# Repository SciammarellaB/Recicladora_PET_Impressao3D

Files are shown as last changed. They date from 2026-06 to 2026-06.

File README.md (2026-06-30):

# Recicladora PET para Impressão 3D

Projeto de TCC voltado ao desenvolvimento de uma recicladora doméstica capaz de
transformar garrafas PET pós-consumo em filamento utilizável em impressoras 3D
FDM.

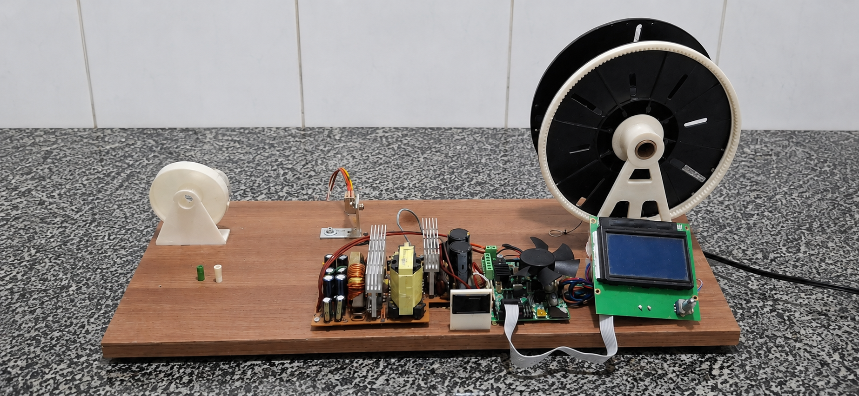
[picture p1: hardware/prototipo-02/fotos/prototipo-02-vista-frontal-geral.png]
Protótipo 02 da recicladora PET


## Índice

- [Sobre o projeto](#sobre-o-projeto)
- [Demonstração de funcionamento](#demonstração-de-funcionamento)
- [Motivação](#motivação)
- [Prova de conceito manual](#prova-de-conceito-manual)
- [Como o processo funciona](#como-o-processo-funciona)
- [Protótipos](#protótipos)
- [Vídeos do projeto](#vídeos-do-projeto)
- [Preparação do PET](#preparação-do-pet)
- [Peças impressas em 3D](#peças-impressas-em-3d)
- [Montagem dos subconjuntos](#montagem-dos-subconjuntos)
- [Extrusão e controle dimensional](#extrusão-e-controle-dimensional)
- [Primeira impressão com PET](#primeira-impressão-com-pet)
- [Controle por G-code](#controle-por-g-code)
- [Anexos e referências](#anexos-e-referências)
- [Estrutura do repositório](#estrutura-do-repositório)
- [Licença](#licença)
- [Observações técnicas](#observações-técnicas)

## Sobre o projeto

A proposta deste projeto é demonstrar, na prática, que uma garrafa PET comum pode
ser preparada, cortada em fitas, extrudada e transformada em material para
impressão 3D.

O foco não está apenas na reciclagem do plástico, mas na construção de um ciclo
completo e acessível: sair de um resíduo cotidiano e chegar a uma peça impressa
funcional. Para isso, o projeto reúne modelagem 3D, reaproveitamento de
componentes de impressora, eletrônica, controle por G-code, testes de extrusão e
ajustes de impressão.

## Demonstração de funcionamento

O vídeo abaixo mostra o equipamento em operação, com a fita PET sendo alimentada
na recicladora, o acionamento do sistema e o início da transformação da fita em
filamento para impressão 3D.

<a href="https://www.youtube.com/shorts/rl4tyrrVXBk" target="_blank" rel="noopener noreferrer">Assistir à demonstração no YouTube</a>

## Motivação

Filamentos comerciais representam um custo recorrente para quem utiliza
impressão 3D. Ao mesmo tempo, garrafas PET são resíduos amplamente disponíveis e
com potencial técnico para reaproveitamento.

A recicladora foi desenvolvida para investigar uma pergunta simples:

> É possível transformar garrafas PET pós-consumo em filamento funcional para
> impressão 3D usando uma solução doméstica, de baixo custo e reproduzível?

O projeto também tem um objetivo educacional: documentar o processo de forma
clara para que outras pessoas possam entender as decisões de construção, os
testes realizados e os limites encontrados.

## Prova de conceito manual

Antes da construção dos protótipos, o primeiro teste foi feito de forma manual
para verificar se o princípio do projeto era possível.

Foi utilizado o bloco gerador de calor do hotend E3D, segurado com um alicate de
pressão, e uma placa RAMPS para controlar o aquecimento. A ideia era simples: se
a fita de PET conseguisse passar pelo bloco aquecido e sair em formato de
filamento, então faria sentido avançar para a construção de uma recicladora com
estrutura, motor, carretel e controle por G-code.

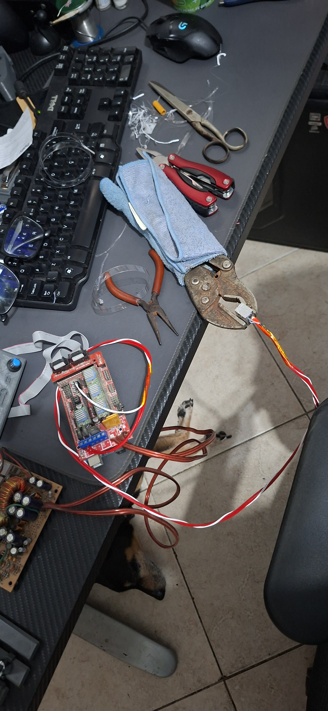
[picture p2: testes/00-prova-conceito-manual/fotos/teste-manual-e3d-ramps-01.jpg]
Prova de conceito manual com bloco E3D e RAMPS


Com o primeiro trecho de filamento puxado manualmente, o material foi testado na
impressora para verificar se o sistema conseguiria aceitá-lo, tanto pelo diâmetro
quanto pela temperatura de trabalho.

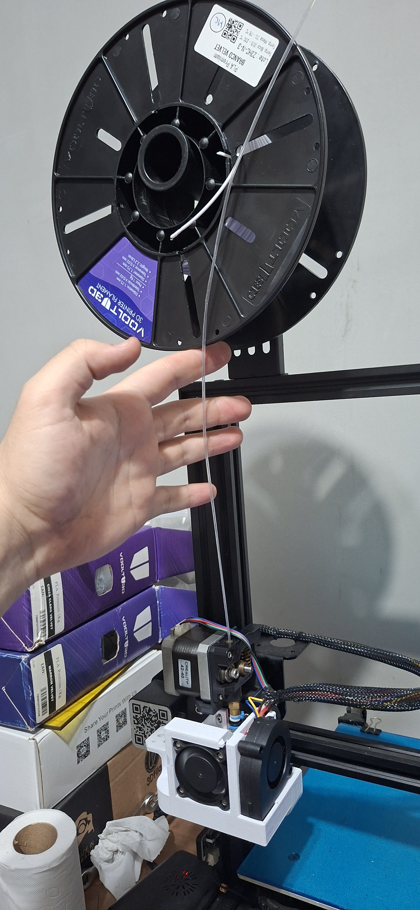
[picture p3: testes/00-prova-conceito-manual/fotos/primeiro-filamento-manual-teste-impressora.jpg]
Primeiro filamento manual sendo testado na impressora


A documentação desta etapa está em
[testes/00-prova-conceito-manual](testes/00-prova-conceito-manual/).

## Como o processo funciona

O processo começa com a seleção e preparação das garrafas. Depois, o PET é
cortado em fitas, aquecido no hotend, conformado em formato de filamento e
enrolado em um carretel adaptado. O material produzido é então testado em uma
impressora 3D, exigindo ajustes próprios de temperatura, fluxo e velocidade.

## Protótipos

### Protótipo 01

O primeiro protótipo validou a montagem inicial do sistema de bobinamento, a
transmissão por engrenagens e o controle eletrônico usando RAMPS 1.4 com Arduino
Mega, LCD compatível com RAMPS e fonte ATX reaproveitada de computador.

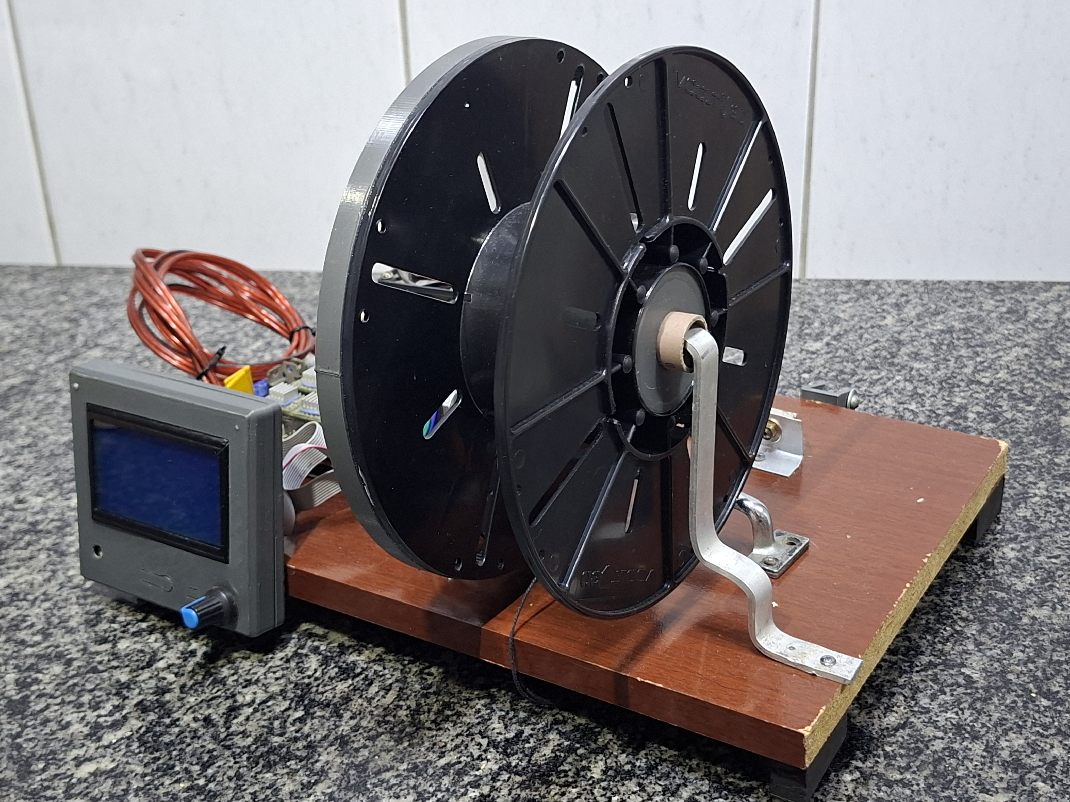
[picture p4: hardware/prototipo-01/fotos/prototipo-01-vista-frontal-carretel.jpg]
Protótipo 01 da recicladora PET


Nesta versão, o equipamento chegou a funcionar de forma estável: bastava iniciar
o G-code e aguardar o processo de extrusão/bobinamento terminar.

Mais fotos e detalhes estão em [hardware/prototipo-01](hardware/prototipo-01/).

### Protótipo 02

O segundo protótipo reorganiza a montagem em uma base maior, separando melhor as
etapas de alimentação do material, aquecimento, eletrônica de controle e
bobinamento.

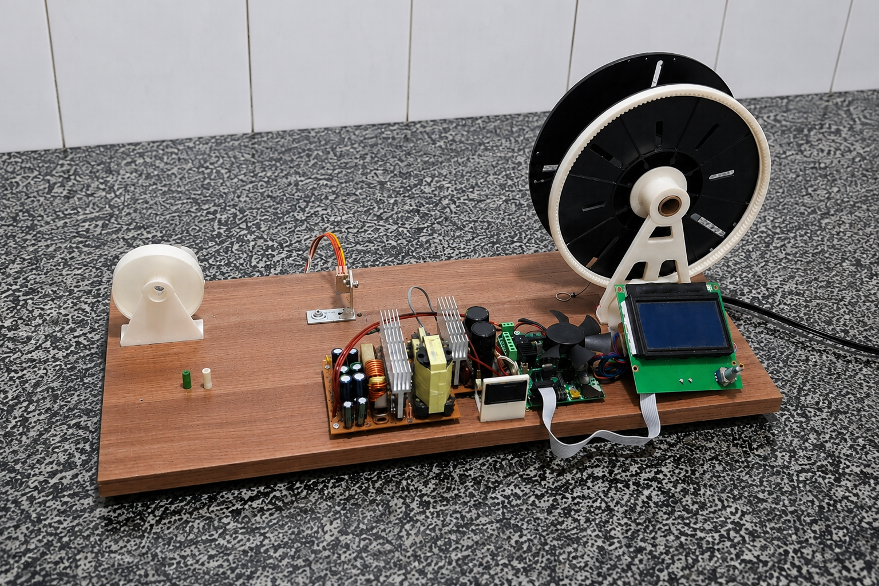
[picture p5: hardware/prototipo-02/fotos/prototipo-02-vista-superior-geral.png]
Protótipo 02 em vista superior


Após montar o conjunto do motor e fixar o carretel nos suportes, foi feito um
teste para verificar o alinhamento e o giro do conjunto mecânico.

Com a montagem validada, o protótipo 2 passou a funcionar corretamente, sem
ajustes pendentes para a operação normal.

Mais fotos e detalhes estão em [hardware/prototipo-02](hardware/prototipo-02/).

## Vídeos do projeto

| Vídeo | Referência no projeto | YouTube |
| --- | --- | --- |
| Protótipo 01 funcionando corretamente | [Protótipo 01](hardware/prototipo-01/#video-de-funcionamento) | <a href="https://youtube.com/shorts/Gr8xRWNqr9U" target="_blank" rel="noopener noreferrer">Assistir</a> |
| Protótipo 02 - teste do motor e carretel | [Teste de montagem](hardware/prototipo-02/#teste-de-montagem) | <a href="https://youtube.com/shorts/MNewDyZXh2g" target="_blank" rel="noopener noreferrer">Assistir</a> |
| Protótipo 02 funcionando corretamente | [Funcionamento correto](hardware/prototipo-02/#funcionamento-correto) | <a href="https://www.youtube.com/watch?v=FplmZ49YgME" target="_blank" rel="noopener noreferrer">Assistir</a> |
| Preparação da garrafa PET para fatiamento | [Preparação do PET](testes/01-preparacao-pet/) | <a href="https://www.youtube.com/shorts/VywLTE21x4Y" target="_blank" rel="noopener noreferrer">Assistir</a> |
| Processo de transformação da fita PET em filamento | [Extrusão e controle dimensional](testes/02-extrusao/) | <a href="https://www.youtube.com/shorts/rl4tyrrVXBk" target="_blank" rel="noopener noreferrer">Assistir</a> |
| Primeira impressão com filamento PET reciclado | [Primeiro teste de impressão](testes/03-impressao-3d/#primeiro-teste-de-impressão) | <a href="https://www.youtube.com/shorts/xxXg9N6lQYA" target="_blank" rel="noopener noreferrer">Assistir</a> |
| Benchy com PET de garrafa colorida | [Teste com PET colorido](testes/03-impressao-3d/#teste-com-pet-colorido) | <a href="https://www.youtube.com/watch?v=Nncd09i17XM" target="_blank" rel="noopener noreferrer">Assistir</a> |
| Impressão do suporte do switch da fita PET | [Peças funcionais](pecas-impressas/funcionais/#suporte-do-switch-da-fita-pet) | <a href="https://youtu.be/djwcRPlRVBY" target="_blank" rel="noopener noreferrer">Assistir</a> |
| Suporte do carretel da fita PET | [Peças funcionais](pecas-impressas/funcionais/#suporte-do-carretel-da-fita-pet) | <a href="https://youtu.be/MDmy_xOUEg0" target="_blank" rel="noopener noreferrer">Assistir</a> |

## Preparação do PET

Antes do corte em tiras, as garrafas precisam ser limpas, secas e preparadas. A
retirada do rótulo é importante para evitar que papel, adesivo, cola ou sujeira
contaminem a fita de PET e cheguem ao hotend durante a extrusão.

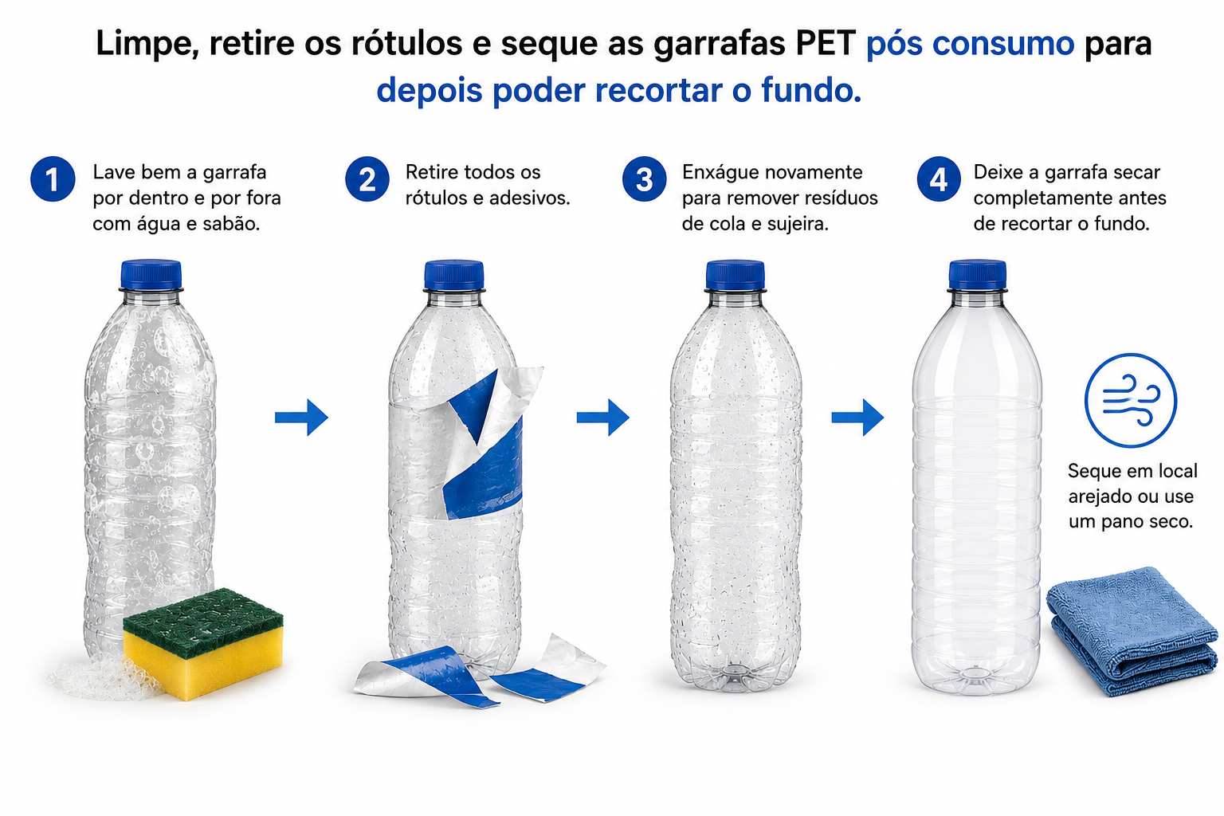
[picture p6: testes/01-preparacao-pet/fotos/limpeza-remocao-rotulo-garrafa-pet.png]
Limpeza e remoção do rótulo da garrafa PET


Depois da limpeza, o fundo da garrafa é removido para permitir o encaixe correto
na ferramenta de corte das tiras de PET.

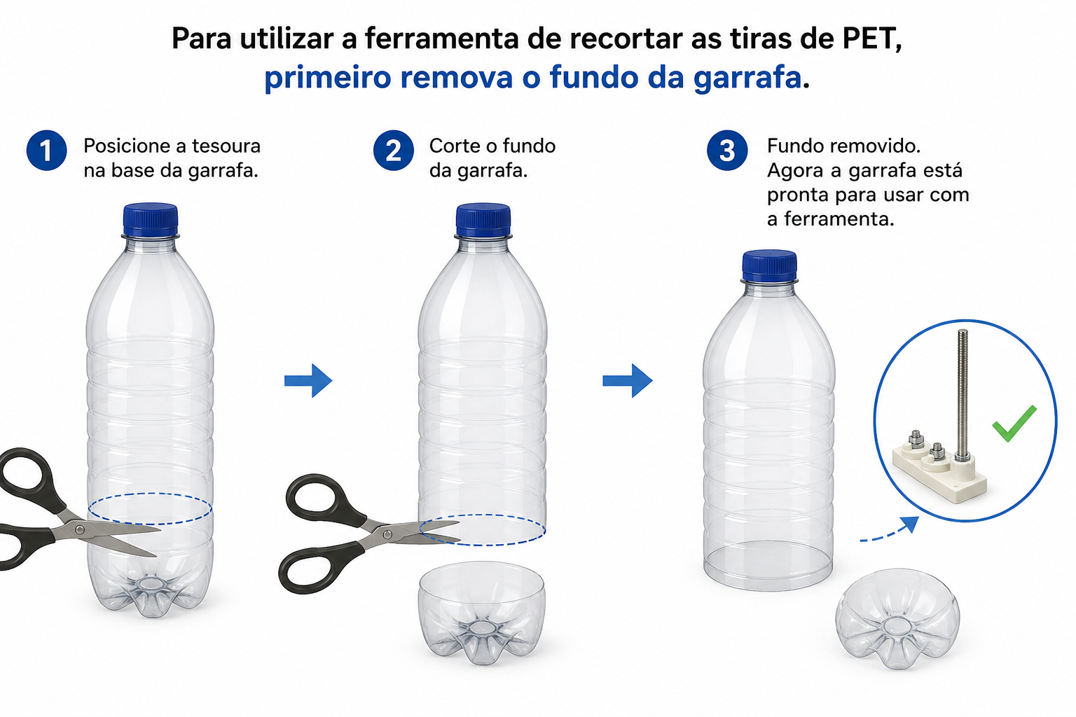
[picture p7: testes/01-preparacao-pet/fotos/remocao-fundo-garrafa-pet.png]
Remoção do fundo da garrafa PET


Para o fatiamento da garrafa em tiras, foi utilizado o projeto
[Simple PET Bottle Cutter](https://makerworld.com/pt/models/98441-simple-pet-bottle-cutter#profileId-111492),
disponivel no MakerWorld.

O vídeo de preparação mostra a limpeza inicial, o corte da garrafa, o fatiamento
do PET em tiras e o enrolamento da fita no carretel.

<a href="https://www.youtube.com/shorts/VywLTE21x4Y" target="_blank" rel="noopener noreferrer">Assistir à preparação da garrafa PET no YouTube</a>

A documentação desta etapa está em
[testes/01-preparacao-pet](testes/01-preparacao-pet/).

## Peças impressas em 3D

As peças estruturais e mecânicas da recicladora foram modeladas no Tinkercad e
impressas em 3D. Elas incluem suporte do motor, suportes dos carretéis,
engrenagens, arruelas adaptadoras e espaçadores.

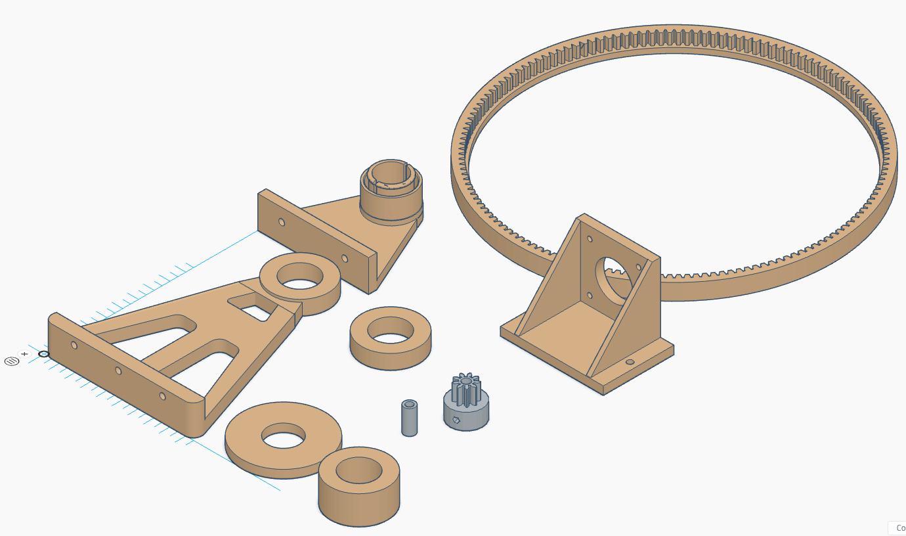
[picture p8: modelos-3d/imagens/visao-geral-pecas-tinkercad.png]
Visão geral das peças no Tinkercad


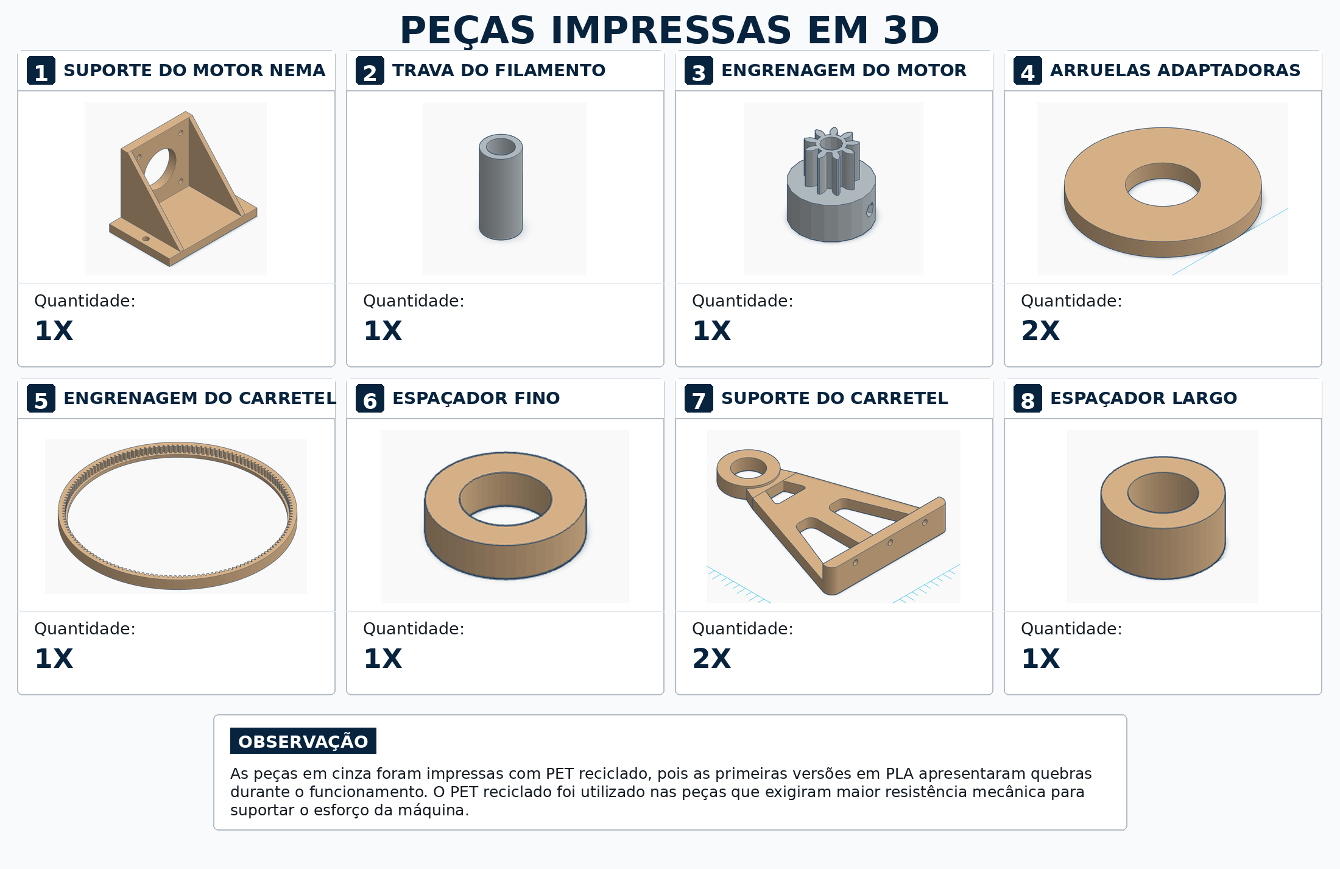
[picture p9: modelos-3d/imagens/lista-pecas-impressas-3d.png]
Lista das peças impressas em 3D


Algumas peças foram posteriormente impressas com PET reciclado, pois versões
iniciais em PLA apresentaram quebras durante o funcionamento. O PET reciclado foi
usado nas peças que exigiam maior resistência mecânica.

A documentação das peças está em [modelos-3d](modelos-3d/), incluindo a tabela
com nomes, quantidades e links para os arquivos STL.

Os registros de aplicação do PET reciclado estão organizados em
[pecas-impressas/testes](pecas-impressas/testes/),
[pecas-impressas/funcionais](pecas-impressas/funcionais/) e
[pecas-impressas/reposicao-prototipo](pecas-impressas/reposicao-prototipo/).

## Montagem dos subconjuntos

### Motor NEMA 17

O motor NEMA 17 é fixado em um suporte impresso em 3D. A engrenagem do motor é
instalada no eixo para transmitir movimento ao sistema de bobinamento.

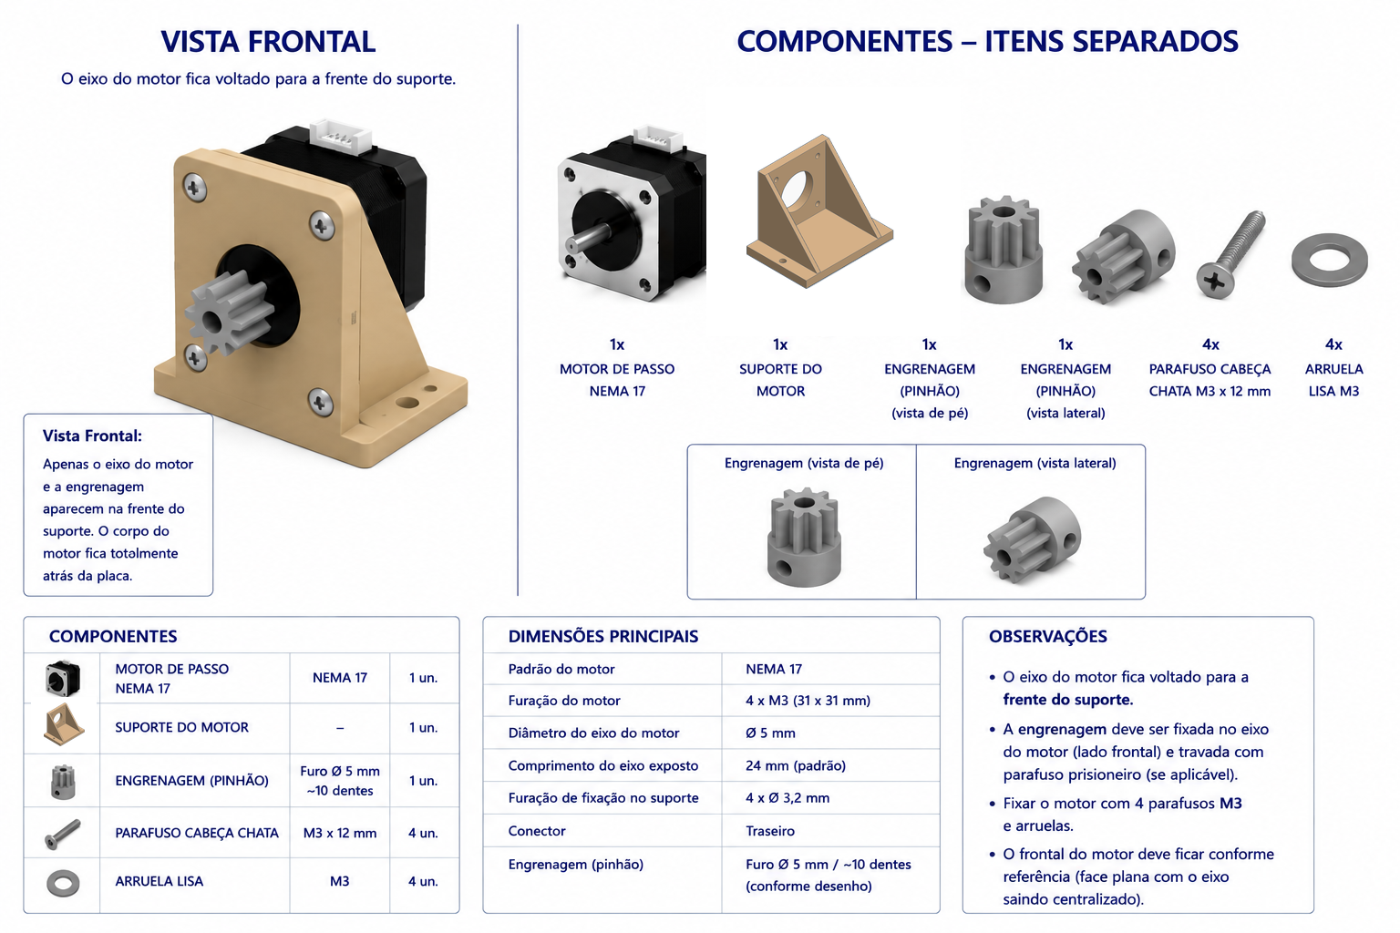
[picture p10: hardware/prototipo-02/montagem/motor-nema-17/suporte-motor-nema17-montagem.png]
Montagem do motor NEMA 17


Detalhes da montagem estão em
[hardware/prototipo-02/montagem/motor-nema-17](hardware/prototipo-02/montagem/motor-nema-17/).

### Carretel

O carretel é reaproveitado de filamento 3D e adaptado com arruelas impressas,
tubo de PVC e uma coroa dentada impressa em 3D.

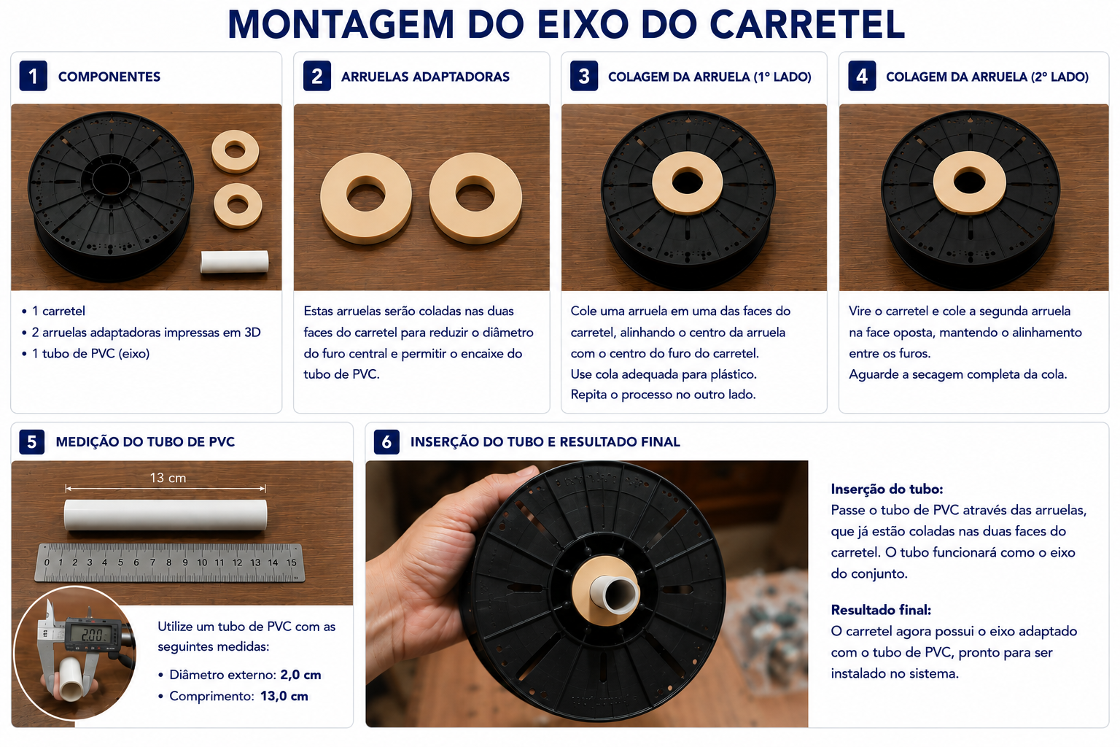
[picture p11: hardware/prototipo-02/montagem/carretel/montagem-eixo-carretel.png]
Montagem do eixo do carretel


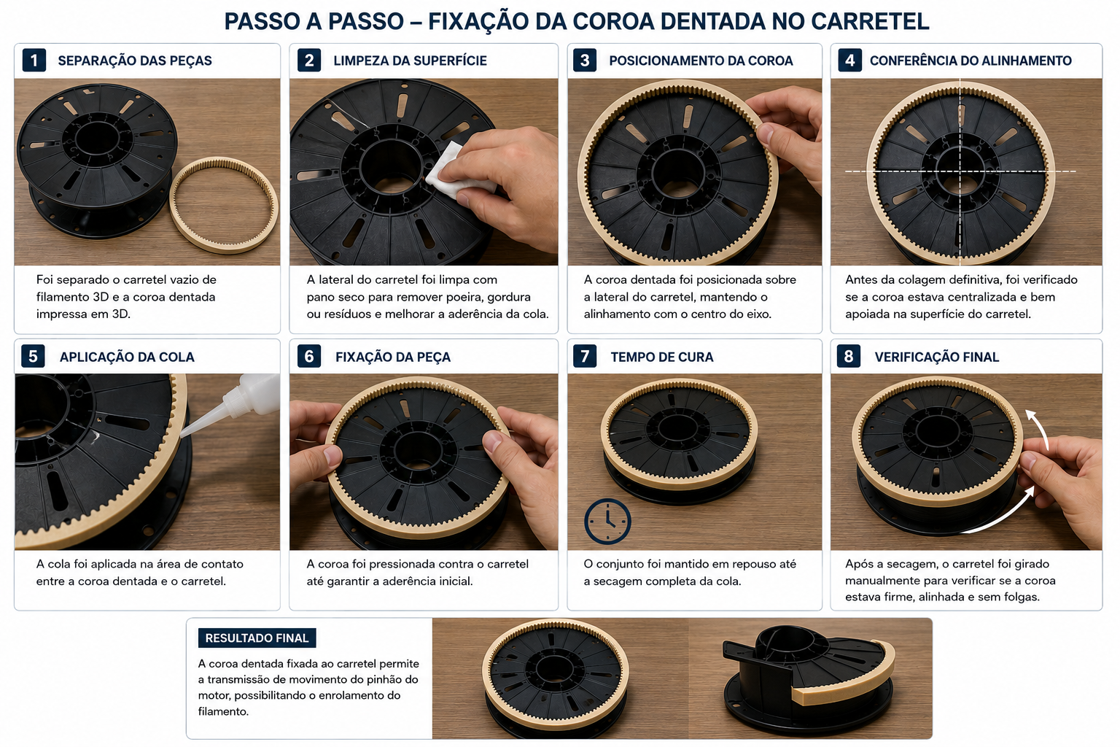
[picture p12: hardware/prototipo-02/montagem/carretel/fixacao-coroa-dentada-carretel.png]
Fixação da coroa dentada no carretel


Detalhes da preparação estão em
[hardware/prototipo-02/montagem/carretel](hardware/prototipo-02/montagem/carretel/).

## Extrusão e controle dimensional

As fitas de PET são aquecidas no hotend e conduzidas até o carretel de
armazenamento. Nos testes, a temperatura de extrusão variou entre 230 °C e
240 °C, com melhor estabilidade observada em 230 °C.

Após o resfriamento, o filamento é medido com paquímetro em diferentes pontos,
tendo como referência o diâmetro nominal de 1,75 mm. Como o filamento é formado
a partir de uma fita PET dobrada e conformada pelo calor, ele pode apresentar
interior oco, ovalização e pequenas variações dimensionais.

A documentação desta etapa está em
[testes/02-extrusao](testes/02-extrusao/). A organização dos dados de medição
está em [dados/medicoes](dados/medicoes/).

## Primeira impressão com PET

Depois dos primeiros testes de geração manual do filamento, o material foi levado
para a impressora 3D. Essa etapa serviu para verificar se a impressora conseguiria
aceitar o filamento produzido, tanto pelo diâmetro quanto pela temperatura de
trabalho.

O primeiro teste de impressão também ajudou a entender quais ajustes seriam
necessários na impressora e no fatiador, como temperatura, fluxo, velocidade e
estabilidade da extrusão.

Também foram feitos testes com garrafas PET coloridas. Um dos ensaios utilizou
um barquinho Benchy para observar se o material ficaria translúcido e se a cor da
garrafa causaria alguma diferença durante a impressão.

A documentação desta etapa está em [testes/03-impressao-3d](testes/03-impressao-3d/).
Os parâmetros de fatiamento usados com PET reciclado estão em
[testes/03-impressao-3d/parametros](testes/03-impressao-3d/parametros/).

## Controle por G-code

Na versão com eletrônica reaproveitada da Ender 3 Pro, a recicladora utiliza a
placa principal e o firmware original da impressora. Não há firmware customizado
gravado na placa.

Os parâmetros necessários para a operação são definidos temporariamente no início
dos arquivos G-code. Isso inclui temperatura do hotend, extrusão relativa,
steps/mm temporário do extrusor, limite de velocidade, aceleração, jerk e
multiplicador de velocidade.

Os G-codes utilizados no projeto trabalham com três temperaturas de extrusão:

| Arquivo | Temperatura | Uso |
| --- | ---: | --- |
| `PET_230c_20m.gcode` | 230 °C | Extrusão em temperatura mais baixa. |
| `PET_235c_20m.gcode` | 235 °C | Extrusão em temperatura intermediária. |
| `PET_240c_20m.gcode` | 240 °C | Extrusão em temperatura mais alta. |

A documentação desta parte está em [codigo/gcode](codigo/gcode/) e a nota sobre
firmware original está em
[codigo/firmware-original-creality.md](codigo/firmware-original-creality.md).

## Anexos e referências

Os links auxiliares da monografia, incluindo cortador de garrafa PET, suporte
para bobinas de tiras e hotend E3D V6, estão reunidos em [anexos](anexos/).

As referências bibliográficas usadas como base teórica e técnica estão em
[docs/referencias](docs/referencias/).

## Estrutura do repositório

```text
.
├── docs/
│   ├── monografia/
│   ├── referencias/
│   └── apresentacoes/
├── hardware/
│   ├── prototipo-01/
│   └── prototipo-02/
├── modelos-3d/
│   ├── stl/
│   └── imagens/
├── codigo/
│   ├── gcode/
│   ├── scripts/
│   └── firmware-original-creality.md
├── testes/
│   ├── 00-prova-conceito-manual/
│   ├── 01-preparacao-pet/
│   ├── 02-extrusao/
│   ├── 03-impressao-3d/
│   └── 04-resistencia/
├── pecas-impressas/
├── dados/
└── anexos/
```

## Licença

Este projeto está licenciado sob a
[Creative Commons Attribution-NonCommercial-ShareAlike 4.0 International](LICENSE)
(CC BY-NC-SA 4.0).

O material pode ser acessado, copiado, compartilhado e adaptado para fins não
comerciais, desde que seja dado o devido crédito ao autor e que trabalhos
derivados sejam distribuídos sob a mesma licença ou uma licença compatível.

Uso comercial não é permitido sem autorização prévia do autor.

## Observações técnicas

- Os arquivos CAD/editáveis dos modelos 3D não são disponibilizados neste
  repositório. Para reprodução, serão fornecidos os arquivos STL.
- O código-fonte do firmware da Creality também não é disponibilizado. A placa e
  o firmware permanecem originais da Ender 3 Pro.
- As alterações de parâmetros da máquina são feitas pelos arquivos G-code, sem
  gravação permanente com `M500`.
- O projeto está em desenvolvimento e este repositório funciona como registro
  técnico, visual e experimental da construção.

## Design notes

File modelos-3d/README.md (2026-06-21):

# Modelos 3D

Esta pasta reune os arquivos e referencias das pecas impressas em 3D usadas na
construcao da recicladora de PET.

As pecas foram modeladas no Tinkercad e impressas para compor a estrutura,
fixacao, tracao e bobinamento do equipamento.

## Imagens de referencia

Visao geral das pecas no Tinkercad

Lista das pecas impressas em 3D

## Lista de pecas impressas

Os arquivos STL ficam todos juntos em [`stl/`](stl/) para facilitar o download e
a impressao das pecas.

| Nº | Peca | Arquivo STL | Quantidade | Observacao |
| ---: | --- | --- | ---: | --- |
| 1 | Suporte do motor NEMA | [`stl/suporte-motor-nema17.stl`](stl/suporte-motor-nema17.stl) | 1x | Suporte estrutural para fixacao do motor NEMA. |
| 2 | Trava do filamento | [`stl/trava-filamento.stl`](stl/trava-filamento.stl) | 1x | Peca de apoio/travamento do caminho do material. |
| 3 | Engrenagem do motor NEMA 17 | [`stl/engrenagem-motor-nema17.stl`](stl/engrenagem-motor-nema17.stl) | 1x | Peca em cinza impressa com PET reciclado apos quebras nas primeiras versoes em PLA. |
| 4 | Arruelas adaptadoras | [`stl/arruela-adaptadora.stl`](stl/arruela-adaptadora.stl) | 2x | Arruelas para ajuste e adaptacao mecanica do conjunto. |
| 5 | Engrenagem do carretel | [`stl/engrenagem-carretel.stl`](stl/engrenagem-carretel.stl) | 1x | Engrenagem grande do sistema de movimentacao do carretel. |
| 6 | Espacador fino | [`stl/espacador-fino.stl`](stl/espacador-fino.stl) | 1x | Espacador para alinhamento do conjunto. |
| 7 | Suporte do carretel bobinador | [`stl/suporte-carretel-bobinador.stl`](stl/suporte-carretel-bobinador.stl) | 1x | Suporte estrutural do carretel que enrola o filamento produzido. |
| 8 | Suporte do carretel da fita PET | [`stl/suporte-carretel-fita-pet.stl`](stl/suporte-carretel-fita-pet.stl) | 1x | Suporte do carretel que armazena/alimenta a fita PET antes da extrusao. |
| 9 | Espacador largo | [`stl/espacador-largo.stl`](stl/espacador-largo.stl) | 1x | Espacador maior para alinhamento do conjunto. |

## Observacao sobre material

As pecas em cinza foram impressas com PET reciclado. As primeiras versoes em PLA
apresentaram quebras durante o funcionamento, entao o PET reciclado foi utilizado
nas pecas que exigiam maior resistencia mecanica para suportar o esforco da
maquina.

## Organizacao dos arquivos

- `stl/`: arquivos prontos para impressao, reunidos em uma unica pasta.
- `imagens/`: capturas e pranchas explicativas das pecas.

## Observacao sobre arquivos editaveis

Os arquivos CAD/editaveis dos modelos nao serao disponibilizados neste repositorio.
Para reproducao do projeto, serao fornecidos apenas os arquivos STL das pecas
necessarias para impressao.

As imagens do Tinkercad ficam como referencia visual para identificar as pecas,
entender o conjunto e conferir quantidades.

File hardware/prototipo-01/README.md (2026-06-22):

# Prototipo 01

Esta pasta documenta a primeira versao montada da recicladora de PET para
impressao 3D.

O prototipo 01 foi construido como uma versao funcional inicial, usando uma base
de madeira, componentes reaproveitados de impressora 3D, pecas impressas em 3D e
um sistema de carretel adaptado para bobinar o filamento produzido.

## Fotos gerais

Prototipo 01 - vista frontal do carretel

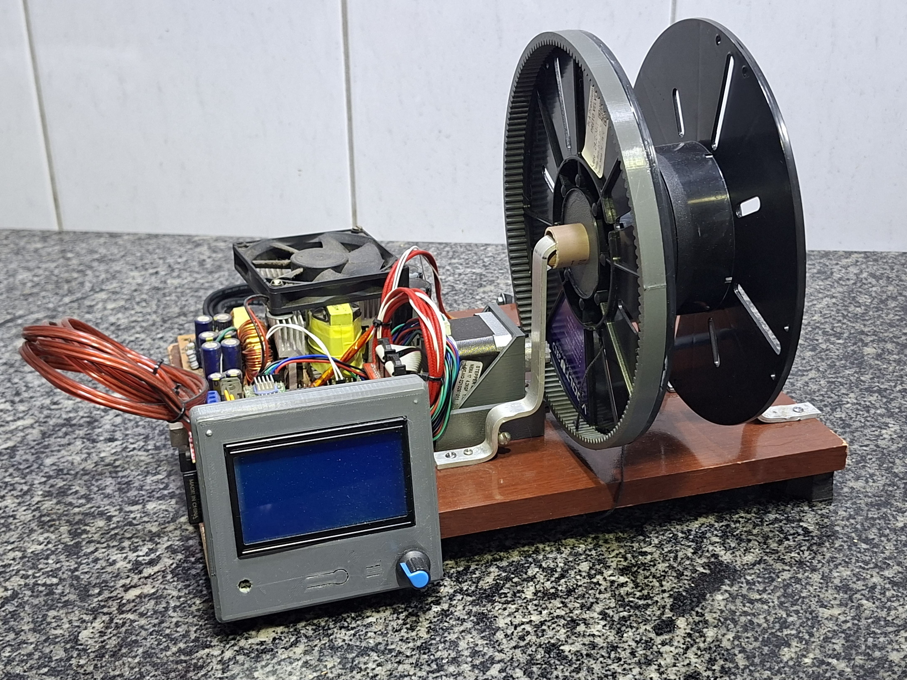
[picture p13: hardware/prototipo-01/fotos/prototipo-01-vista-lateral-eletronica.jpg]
Prototipo 01 - vista lateral com eletronica


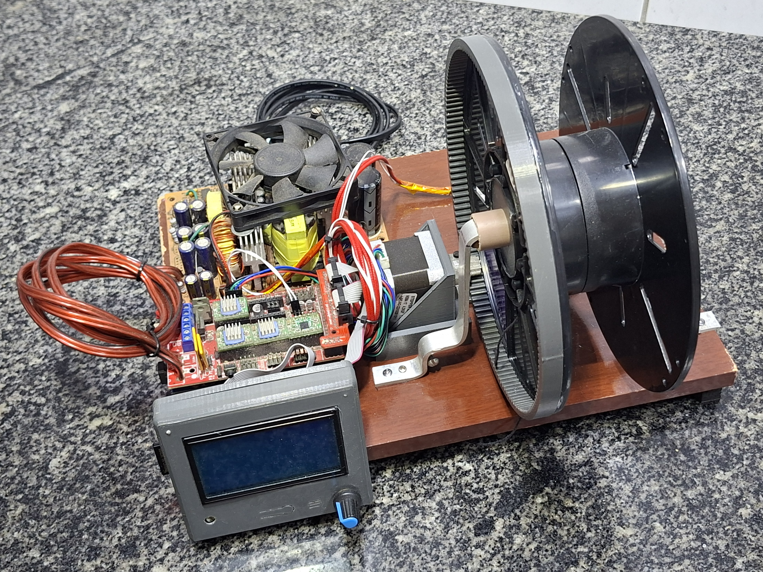
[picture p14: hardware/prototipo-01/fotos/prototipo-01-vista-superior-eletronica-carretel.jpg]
Prototipo 01 - vista superior da eletronica e carretel


## Video de funcionamento

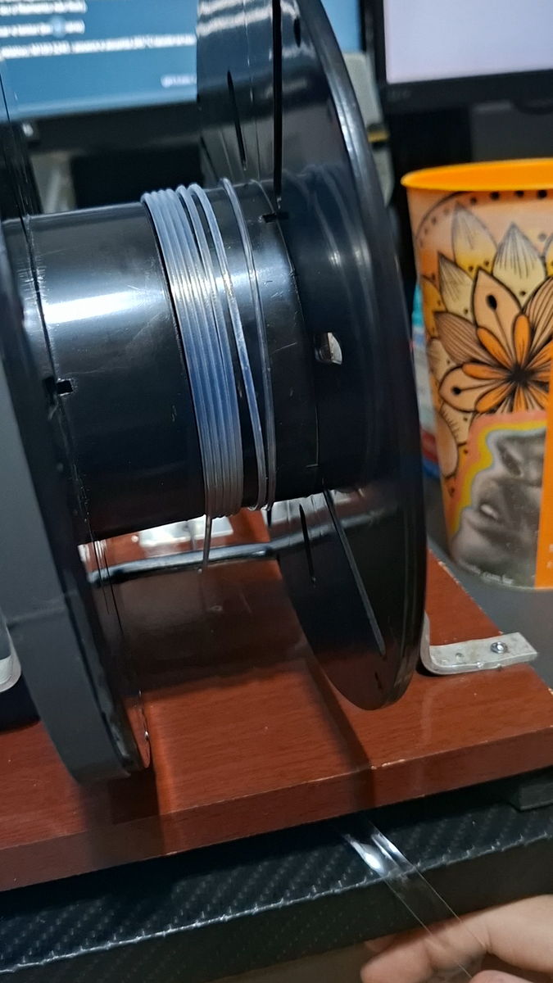
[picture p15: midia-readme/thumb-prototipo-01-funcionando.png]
Prototipo 01 funcionando corretamente


<a href="https://youtube.com/shorts/Gr8xRWNqr9U" target="_blank" rel="noopener noreferrer">Assistir no YouTube</a>

Neste registro, o prototipo 01 ja estava operando de forma estavel. A recicladora
conseguia executar o processo normalmente: iniciar o G-code, aguardar o aquecimento
e deixar o equipamento trabalhar ate o fim da extrusao/bobinamento.

## Componentes visiveis

- Base de madeira usada como estrutura principal.
- Carretel reaproveitado para enrolamento do filamento.
- Coroa dentada fixada ao carretel.
- Motor de passo NEMA 17.
- Engrenagem do motor para transmissao de movimento ao carretel.
- Suportes metalicos e pecas impressas em 3D para fixacao.
- Display LCD compativel com RAMPS.
- Placa controladora RAMPS 1.4 com Arduino Mega.
- Fonte ATX reaproveitada de computador para alimentacao do conjunto.

## Funcao desta versao

O objetivo do prototipo 01 foi validar a montagem fisica do sistema de
bobinamento usando eletronica baseada em RAMPS 1.4 com Arduino Mega. A partir
dessa versao, foi possivel testar o acionamento do motor, o alinhamento do
carretel, a transmissao por engrenagens e a operacao por G-code.

## Observacoes de projeto

- A eletronica desta etapa ainda usava RAMPS 1.4 com Arduino Mega e LCD
  compativel com RAMPS.
- A placa e o LCD da Creality/Ender 3 Pro ainda nao faziam parte desta versao.
- Os parametros de operacao sao ajustados temporariamente nos arquivos G-code.
- A base de madeira facilitou ajustes de posicao, fixacao e alinhamento durante
  a prototipagem.
- O carretel foi adaptado com eixo de PVC, arruelas impressas em 3D e coroa
  dentada colada na lateral.

## Subpastas

- `fotos/`: registros fotograficos do prototipo montado.

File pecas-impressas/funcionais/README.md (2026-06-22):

# Pecas funcionais

Esta pasta documenta pecas funcionais impressas com o filamento PET reciclado
produzido no projeto.

Depois dos primeiros testes de calibracao, o filamento foi usado em pecas com
aplicacao pratica, incluindo ganchos e componentes mecanicos de projetos
auxiliares.

## Exemplos documentados na monografia

| Peca | Foto | Finalidade |
| --- | --- | --- |
| Gancho em formato de S | [`fotos/gancho-s-pet-reciclado.jpg`](fotos/gancho-s-pet-reciclado.jpg) | Teste de aplicacao domestica para pendurar mochila, sacolas e outros itens. |
| Engrenagens para eixo planetario | [`fotos/engrenagens-pet-reciclado.jpg`](fotos/engrenagens-pet-reciclado.jpg) | Teste mecanico com geometrias funcionais. |
| Conjunto de engrenagens planetario | [`fotos/conjunto-engrenagens-planetario-pet-reciclado.jpg`](fotos/conjunto-engrenagens-planetario-pet-reciclado.jpg) | Avaliacao de montagem e funcionamento em conjunto mecanico. |
| Suporte do switch da fita PET | [`fotos/suporte-switch-fita-pet-montado-01.jpg`](fotos/suporte-switch-fita-pet-montado-01.jpg) | Suporte para montagem do switch usado no caminho da fita PET. |
| Suporte do carretel da fita PET | [`fotos/suporte-carretel-fita-pet-01.jpg`](fotos/suporte-carretel-fita-pet-01.jpg) | Suporte para o carretel que armazena e alimenta a fita PET. |

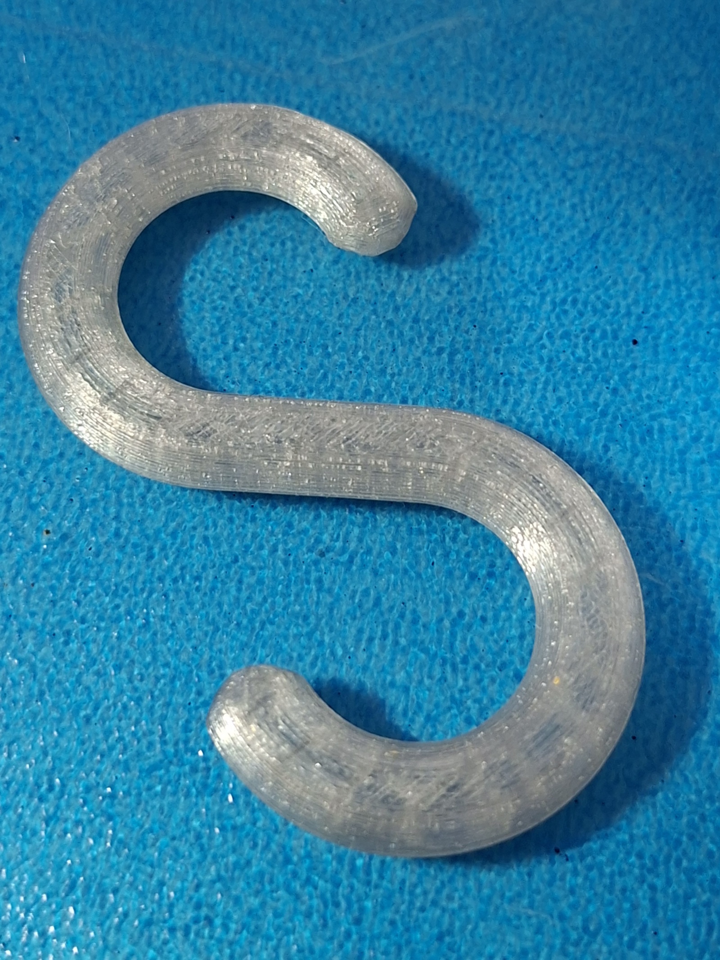
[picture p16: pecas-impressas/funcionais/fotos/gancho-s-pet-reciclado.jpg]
Gancho em formato de S impresso com PET reciclado


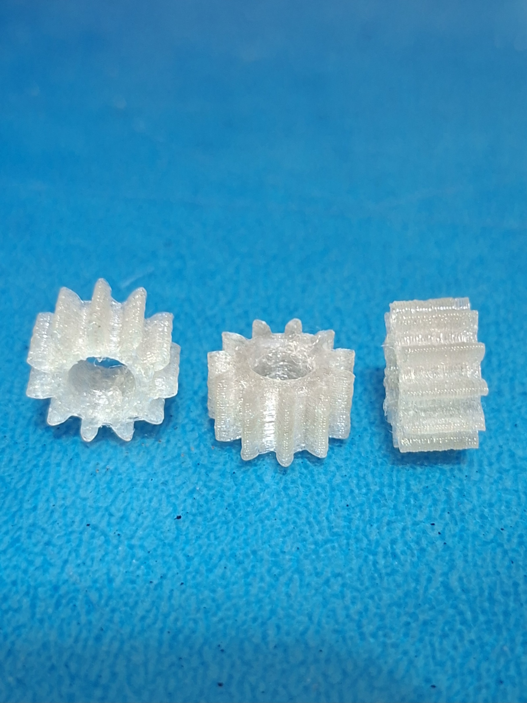
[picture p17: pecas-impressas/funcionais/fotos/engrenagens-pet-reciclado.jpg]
Engrenagens impressas com PET reciclado


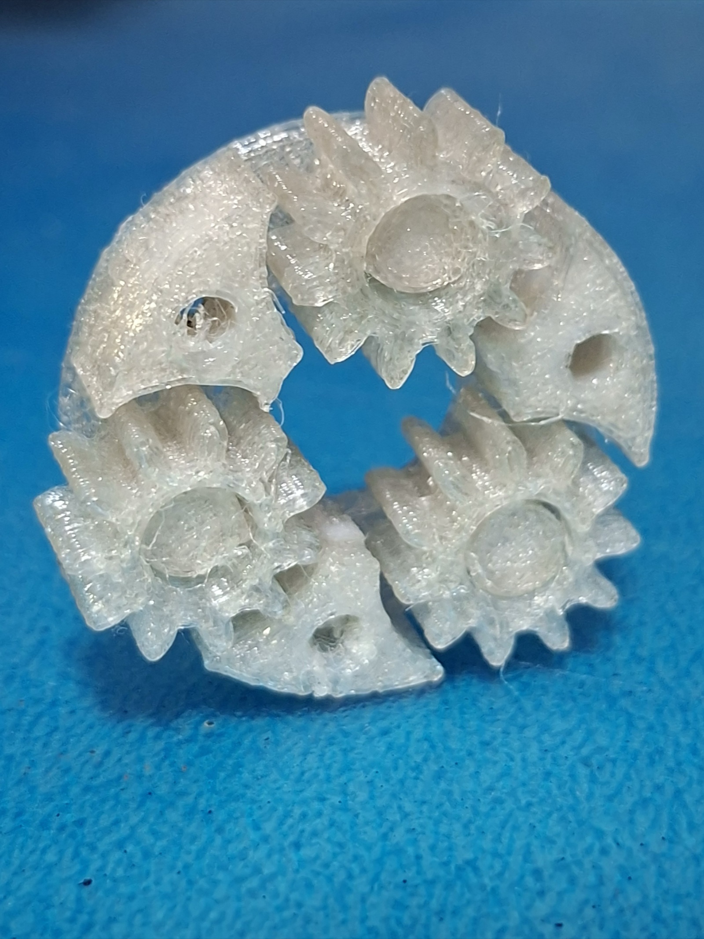
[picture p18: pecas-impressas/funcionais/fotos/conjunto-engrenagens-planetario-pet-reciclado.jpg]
Conjunto de engrenagens planetario impresso com PET reciclado


## Suporte do switch da fita PET

<a href="https://youtu.be/djwcRPlRVBY" target="_blank" rel="noopener noreferrer">
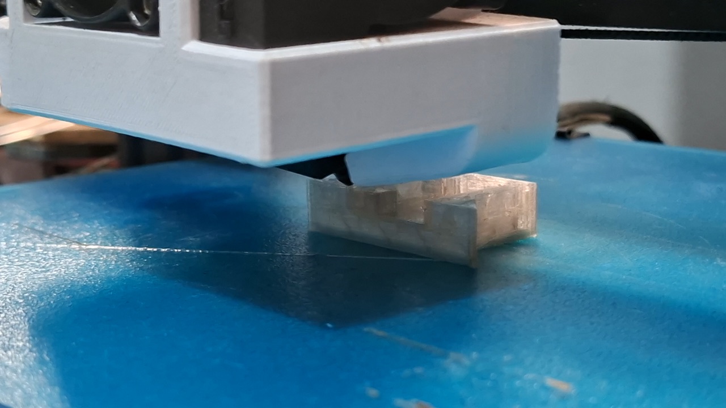
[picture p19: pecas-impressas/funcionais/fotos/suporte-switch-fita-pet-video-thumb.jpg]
Impressao do suporte do switch da fita PET
  
</a>

<a href="https://youtu.be/djwcRPlRVBY" target="_blank" rel="noopener noreferrer">Assistir no YouTube</a>

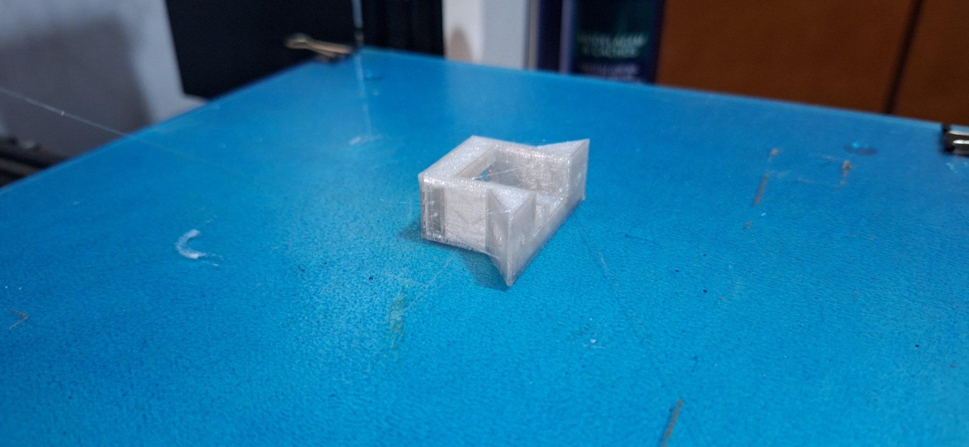
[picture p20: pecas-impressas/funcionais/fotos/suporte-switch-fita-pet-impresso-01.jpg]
Suporte do switch da fita PET impresso


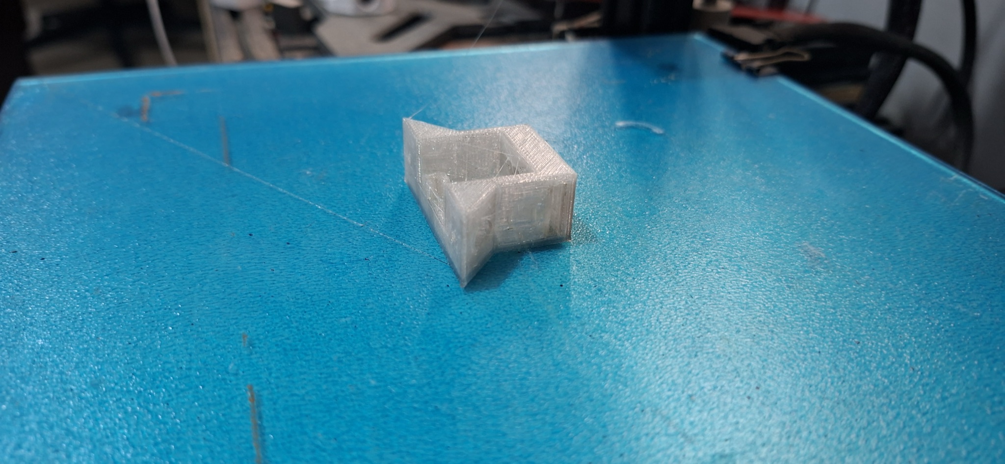
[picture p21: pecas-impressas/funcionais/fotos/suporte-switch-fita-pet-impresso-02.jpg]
Suporte do switch da fita PET impresso em outro angulo


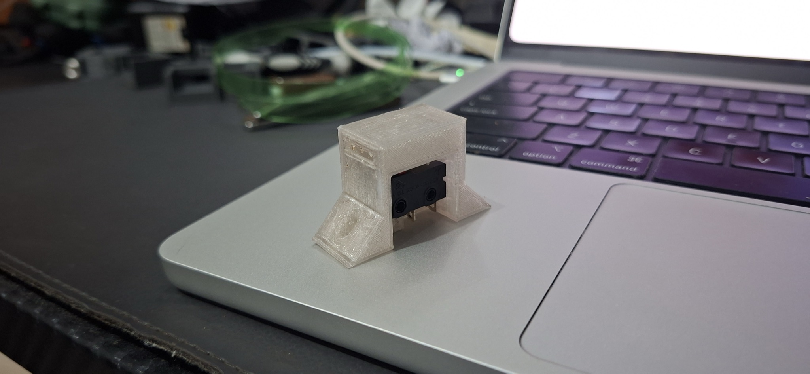
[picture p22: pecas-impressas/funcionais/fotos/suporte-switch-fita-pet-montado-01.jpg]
Suporte do switch da fita PET montado


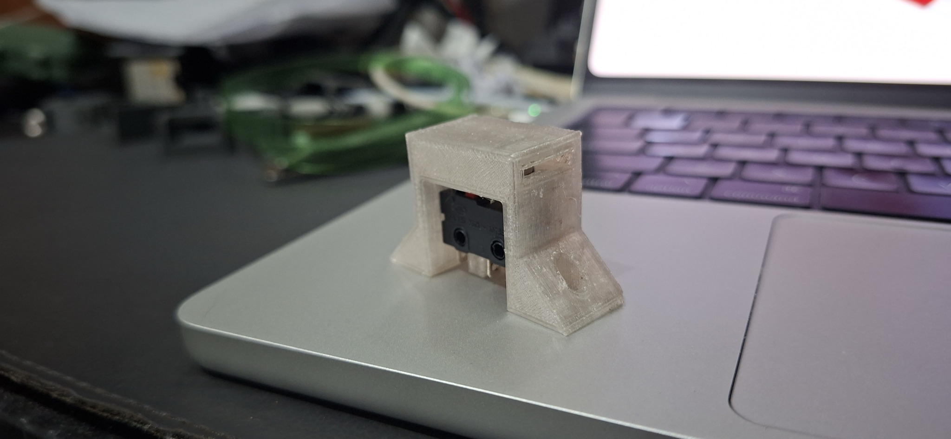
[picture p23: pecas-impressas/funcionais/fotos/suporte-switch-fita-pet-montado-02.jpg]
Suporte do switch da fita PET montado em outro angulo


## Suporte do carretel da fita PET

<a href="https://youtu.be/MDmy_xOUEg0" target="_blank" rel="noopener noreferrer">
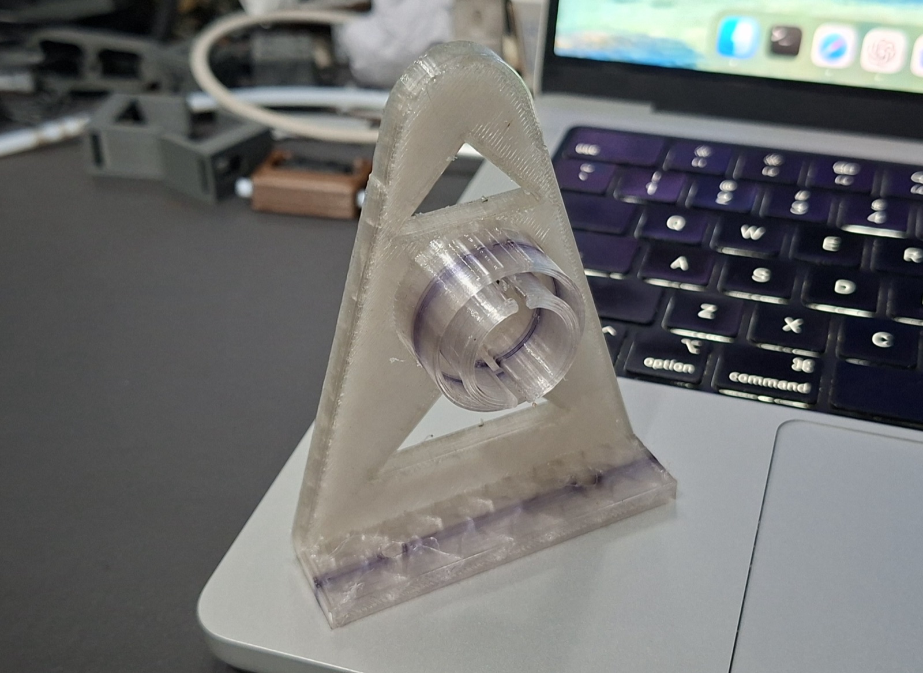
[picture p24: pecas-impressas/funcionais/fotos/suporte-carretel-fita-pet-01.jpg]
Suporte do carretel da fita PET
  
</a>

<a href="https://youtu.be/MDmy_xOUEg0" target="_blank" rel="noopener noreferrer">Assistir no YouTube</a>

Suporte do carretel da fita PET em vista frontal

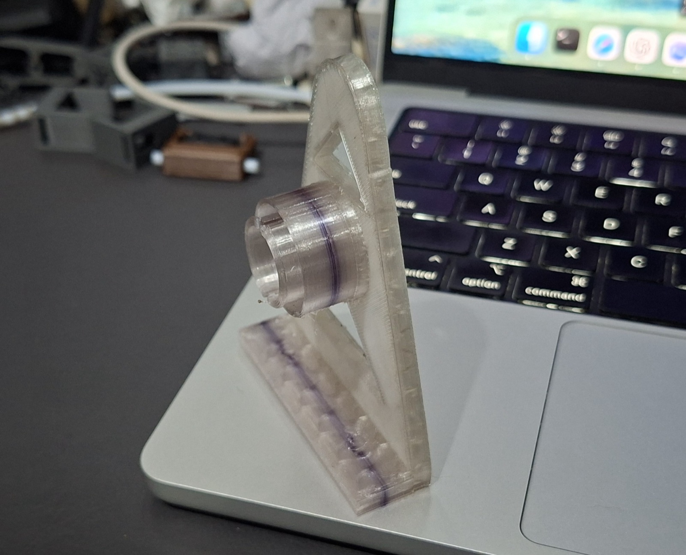
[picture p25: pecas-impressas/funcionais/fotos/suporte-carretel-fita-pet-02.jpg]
Suporte do carretel da fita PET em vista lateral


## Pontos avaliados

- resistencia percebida durante o uso;
- estabilidade dimensional;
- acabamento visual;
- fusao entre camadas;
- adequacao do material para pecas com funcao mecanica ou domestica.

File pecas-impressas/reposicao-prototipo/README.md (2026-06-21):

# Pecas de reposicao do prototipo

Esta pasta documenta pecas do proprio prototipo que foram substituidas por
versoes impressas com PET reciclado.

Durante o uso do equipamento, algumas pecas impressas inicialmente com materiais
convencionais, especialmente PLA, apresentaram desgaste prematuro ou quebra.
Nesses casos, o filamento PET reciclado produzido pelo projeto foi usado para
fabricar novas versoes das pecas.

## Exemplo documentado

| Peca | Foto | Motivo da substituicao | Material usado na reposicao |
| --- | --- | --- | --- |
| Engrenagem do motor NEMA 17 | [`fotos/engrenagem-motor-nema17-pet-reciclado.jpg`](fotos/engrenagem-motor-nema17-pet-reciclado.jpg) | Quebra ou desgaste durante o funcionamento do prototipo | PET reciclado produzido no projeto |

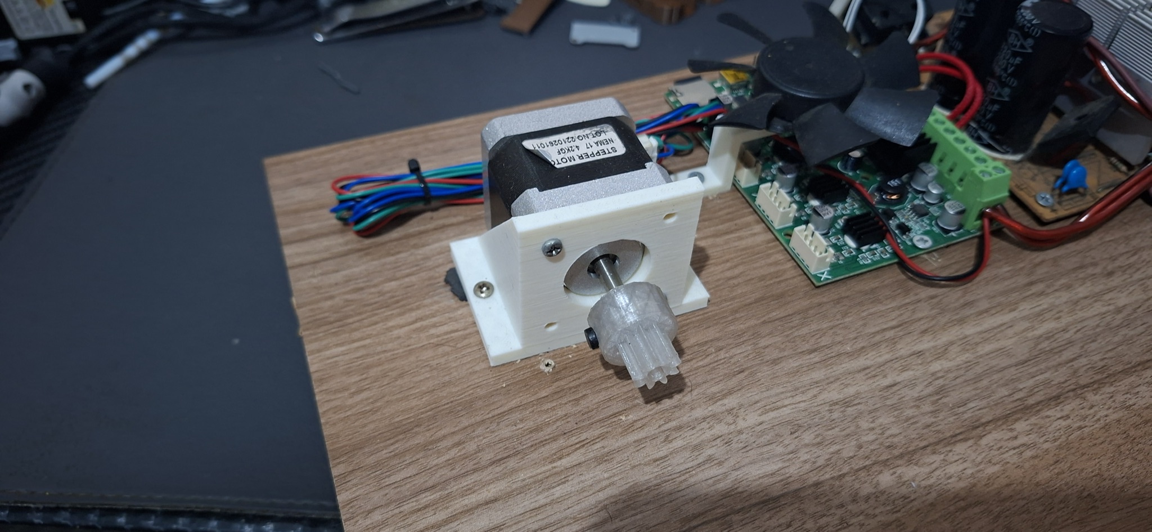
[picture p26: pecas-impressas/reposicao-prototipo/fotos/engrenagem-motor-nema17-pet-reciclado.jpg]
Engrenagem do motor NEMA 17 impressa com PET reciclado


## Relevancia

Essa reposicao demonstra uma aplicacao direta do material produzido: o filamento
reciclado nao foi usado apenas em corpos de prova, mas tambem em uma peca
funcional do proprio equipamento.

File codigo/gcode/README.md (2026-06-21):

# G-codes da recicladora

Esta pasta deve conter os arquivos G-code usados para operar a recicladora de PET.
Eles controlam o aquecimento do hotend, habilitam os motores e executam a extrusao
continua da fita de PET em blocos, evitando comandos muito longos de extrusao.

A recicladora utiliza a placa principal e o firmware original de uma Ender 3 Pro.
Por esse motivo, os ajustes necessarios para a operacao do equipamento nao sao
gravados como alteracoes permanentes de firmware. As sobrecargas de valores e
parametros sao aplicadas diretamente pelos arquivos G-code durante a execucao.

## Arquivos usados

| Arquivo | Temperatura do bico | Finalidade |
| --- | ---: | --- |
| `PET_230c_20m.gcode` | 230 C | Extrusao de aproximadamente 20 m de material em temperatura mais baixa. |
| `PET_235c_20m.gcode` | 235 C | Extrusao de aproximadamente 20 m de material em temperatura intermediaria. |
| `PET_240c_20m.gcode` | 240 C | Extrusao de aproximadamente 20 m de material em temperatura mais alta. |

## Logica geral dos arquivos

Os tres arquivos seguem a mesma estrutura. A diferenca principal entre eles e a
temperatura configurada para o hotend.

Comandos principais:

- `M104 S...`: define a temperatura do bico.
- `M109 S...`: aguarda o bico atingir a temperatura configurada.
- `M17`: habilita os motores.
- `M83`: configura extrusao relativa.
- `M92 E175`: define temporariamente os steps/mm do extrusor, sem salvar com `M500`.
- `M203 E5`: limita a velocidade maxima do extrusor.
- `M201 E500`: define aceleracao do extrusor.
- `M205 E2`: define jerk do extrusor.
- `M220 S100`: mantem o multiplicador de velocidade em 100%.
- `G1 E190 F125`: executa blocos de extrusao do material.

## Observacoes de uso

- Os arquivos foram criados para uso na recicladora construida a partir de
  componentes reaproveitados de uma Ender 3 Pro original.
- A placa e o firmware permanecem originais; os parametros sao sobrescritos
  temporariamente pelo proprio G-code.
- A selecao entre 230 C, 235 C e 240 C permite testar o comportamento do PET em
  diferentes condicoes de fusao e conformacao.
- Nos testes documentados na monografia, 230 C apresentou a condicao mais
  estavel, com melhor acabamento superficial, aspecto mais cristalino e formato
  dimensional mais uniforme.
- Os blocos repetidos de `G1 E190 F125` ajudam a evitar problemas de firmware
  relacionados a comandos de extrusao muito longos.
- Os ajustes de temperatura e velocidade devem ser acompanhados por medicoes do
  diametro do filamento e observacao visual do acabamento superficial.

## Pendencias para documentacao

Quando os arquivos estiverem no repositorio, registrar tambem:

1. Qual temperatura gerou o filamento mais estavel.
2. Qual temperatura apresentou melhor acabamento visual.
3. Qual temperatura resultou em melhor impressao 3D posteriormente.
4. Em quais condicoes cada arquivo deve ser escolhido.
5. Se houve diferenca perceptivel entre garrafas de marcas, cores ou espessuras
   diferentes.

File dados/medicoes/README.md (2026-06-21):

# Medicoes e metrologia

Esta pasta deve concentrar os dados medidos durante os testes de preparacao,
extrusao e impressao com PET reciclado.

Na monografia, a etapa de metrologia foi usada para estimar o rendimento do
material preparado e avaliar a regularidade dimensional do filamento produzido.

## Dados recomendados

| Campo | Descricao |
| --- | --- |
| Identificacao da amostra | Codigo ou nome usado para identificar a garrafa ou lote. |
| Volume da garrafa | Volume nominal da embalagem usada no teste. |
| Massa bruta | Massa inicial da garrafa antes da preparacao. |
| Massa util | Massa aproveitavel apos limpeza, remocao de rotulo e corte. |
| Metragem de fita | Comprimento aproximado da fita PET obtida. |
| Largura da fita | Largura configurada na ferramenta de corte. |
| Temperatura de extrusao | Temperatura usada no hotend durante o teste. |
| Massa de filamento | Massa final de filamento produzido. |
| Diametro medio | Media das medicoes do filamento resfriado. |
| Variacao dimensional | Diferenca observada entre medicoes minimas e maximas. |
| Observacoes | Ovalizacao, irregularidades, rompimentos ou estabilidade visual. |

## Instrumentos usados

- paquimetro;
- balanca de cozinha com precisao de 0,1 g;
- observacao visual do acabamento superficial;
- registro fotografico dos testes.

## Limitacoes

As medicoes possuem carater experimental. Os resultados podem sofrer variacao por
conta da precisao dos instrumentos, da espessura da garrafa, da largura da fita,
da umidade residual, da temperatura aplicada e da estabilidade do bobinamento.

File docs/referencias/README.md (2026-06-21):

# Referencias bibliograficas

Esta pasta reune as referencias usadas como base teorica e tecnica da monografia
do projeto.

## Referencias

- BAECHLER, Christian; DEVUONO, Matthew; PEARCE, Joshua M. Distributed recycling
  of waste polymer into RepRap feedstock. Sustainable Materials and
  Technologies, v. 1-2, p. 24-29, 2014. Disponivel em:
  https://www.sciencedirect.com/science/article/pii/S2468067218300208

- CYTRYNBAUM, Natan. Sistema de reciclagem de residuos provenientes de
  manufatura aditiva, visando a producao de filamentos destinados a impressao
  3D. 2021. Trabalho de Conclusao de Curso (Engenharia de Controle e
  Automacao) - Centro Federal de Educacao Tecnologica Celso Suckow da Fonseca
  (CEFET-RJ), Rio de Janeiro, 2021. Disponivel em:
  https://www.cefet-rj.br/attachments/article/2943/Sistema%20Reciclagem_Res%C3%ADduos%20Provenientes%20de%20Manufatura%20Aditiva%20visando%20Produ%C3%A7%C3%A3o%20Filam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

- MEO, Sultan Ayoub. Anatomy and physiology of a scientific paper. Saudi Journal
  of Biological Sciences, v. 25, n. 7, p. 1278-1283, 2018. DOI:
  10.1016/j.sjbs.2018.01.004. Disponivel em:
  https://doi.org/10.1016/j.sjbs.2018.01.004

- PRECIOUS PLASTIC. Precious Plastic: A global community of plastic recyclers.
  Eindhoven: Precious Plastic, 2023. Disponivel em:
  https://www.preciousplastic.com/

- PRINT IT 3D. Print It 3D: guia de impressao 3D e manufatura digital. Sao
  Paulo, 2024. Disponivel em: https://www.printit3d.com.br/

- SOMENZI, Andre. Utilizacao de filamento reciclado de garrafas PET em impressao
  3D: uma aplicacao Design Science Research. 2022. Trabalho de Conclusao de
  Curso (Tecnologo em Processos de Producao e Sistemas) - Instituto Federal de
  Educacao, Ciencia e Tecnologia do Rio Grande do Sul (IFRS), Porto Alegre,
  2022. Disponivel em: https://dspace.ifrs.edu.br/xmlui/handle/123456789/1621

- SOARES, Bruna. Projeto de aluno e docentes transforma garrafas PET em fios
  para impressora 3D em parceria com a UFPR. Universidade Federal do Parana,
  Curitiba, 21 abr. 2022. Disponivel em:
  https://ufpr.br/projeto-de-aluno-e-docentes-transformam-garrafas-pet-em-fios-para-impressora-3d/

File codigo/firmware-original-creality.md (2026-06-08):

# Firmware original da Creality

A recicladora utiliza a placa principal e o firmware original de uma Ender 3 Pro.
Nao ha firmware customizado gravado na placa nesta versao do projeto.

O codigo-fonte do firmware da Creality nao e disponibilizado neste repositorio.
Este projeto documenta apenas a forma como a placa original foi reaproveitada e
controlada por arquivos G-code especificos.

## Estrategia de controle

Como o firmware permanece original, os parametros necessarios para a recicladora
funcionar sao definidos temporariamente no inicio de cada G-code, localizado em:

```text
codigo/gcode/
```

Isso inclui:

- temperatura do hotend;
- habilitacao dos motores;
- modo de extrusao relativa;
- steps/mm temporario do extrusor;
- limite de velocidade do extrusor;
- aceleracao;
- jerk;
- multiplicador de velocidade.

Essa abordagem permite reaproveitar a placa da Ender 3 Pro sem modificar o
firmware de fabrica. Ao mesmo tempo, mantem os testes mais simples, porque cada
arquivo G-code representa uma condicao de operacao especifica da recicladora.

## Observacao importante

Os comandos usados nos G-codes alteram o comportamento da maquina durante a
execucao, mas nao devem ser tratados como configuracoes permanentes, pois nao
sao salvos com `M500`.

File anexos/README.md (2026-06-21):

# Anexos e recursos complementares

Esta pasta reune links e recursos auxiliares relacionados ao projeto.

## Anexos da monografia

| Anexo | Recurso | Link |
| --- | --- | --- |
| A | Arquivos para impressao, codigos personalizados e documentacao do projeto | https://github.com/SciammarellaB/Recicladora_PET_Impressao3D |
| B | Cortador de Garrafa PET Simples | https://makerworld.com/pt/models/98441-simple-pet-bottle-cutter#profileId-111492 |
| C | Bobinador e suporte para bobinas de tiras de PET | https://makerworld.com/pt/models/98447-pet-strip-spooler-and-spool-holder#profileId-107332 |
| D | Hotend E3D V6 | https://e3d-online.com/blogs/news/the-e3d-v6-hotend-design-and-details |

## Registros audiovisuais

Os videos do projeto foram publicados no YouTube como nao listados e estao
referenciados no README principal do repositorio.

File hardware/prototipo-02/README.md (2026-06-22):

# Prototipo 02

Esta pasta documenta a segunda versao da recicladora de PET para impressao 3D.

O prototipo 02 reorganiza a montagem em uma base mais ampla, mantendo a proposta
de reaproveitamento de componentes de impressora 3D e o sistema de bobinamento
com carretel adaptado.

## Fotos gerais

Prototipo 02 - vista frontal geral

Prototipo 02 - vista superior geral

## Teste de montagem

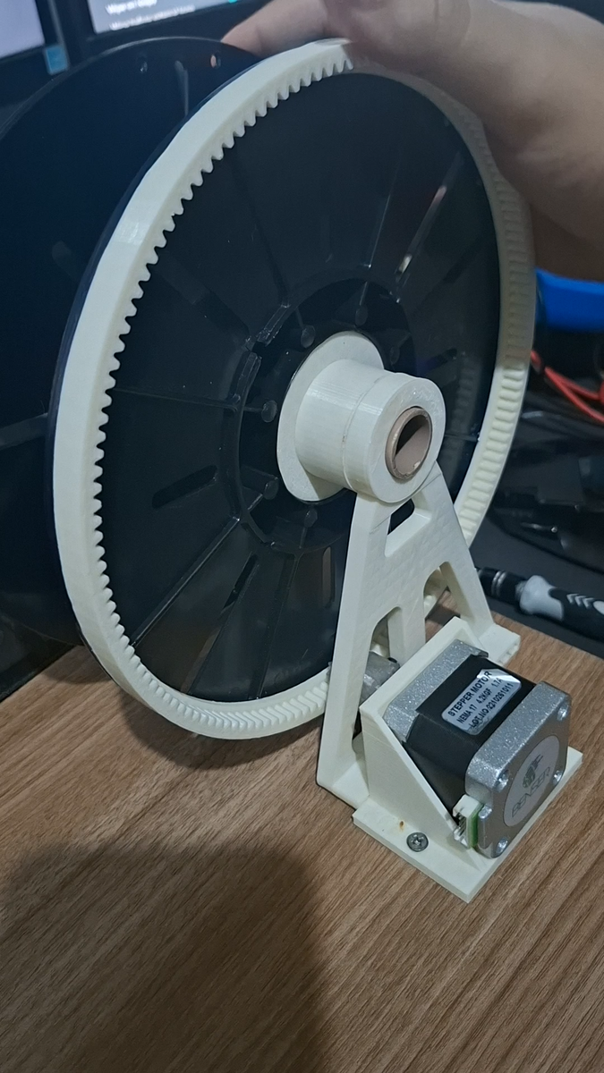
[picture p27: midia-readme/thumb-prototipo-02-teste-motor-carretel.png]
Teste de montagem do motor e carretel no prototipo 02


<a href="https://youtube.com/shorts/MNewDyZXh2g" target="_blank" rel="noopener noreferrer">Assistir no YouTube</a>

Este registro mostra o teste logo apos a montagem do conjunto do motor e a
fixacao do carretel nos suportes. A etapa serviu para conferir se o conjunto
mecanico estava alinhado e se o carretel poderia girar corretamente antes da
integracao completa com o restante do equipamento.

## Funcionamento correto

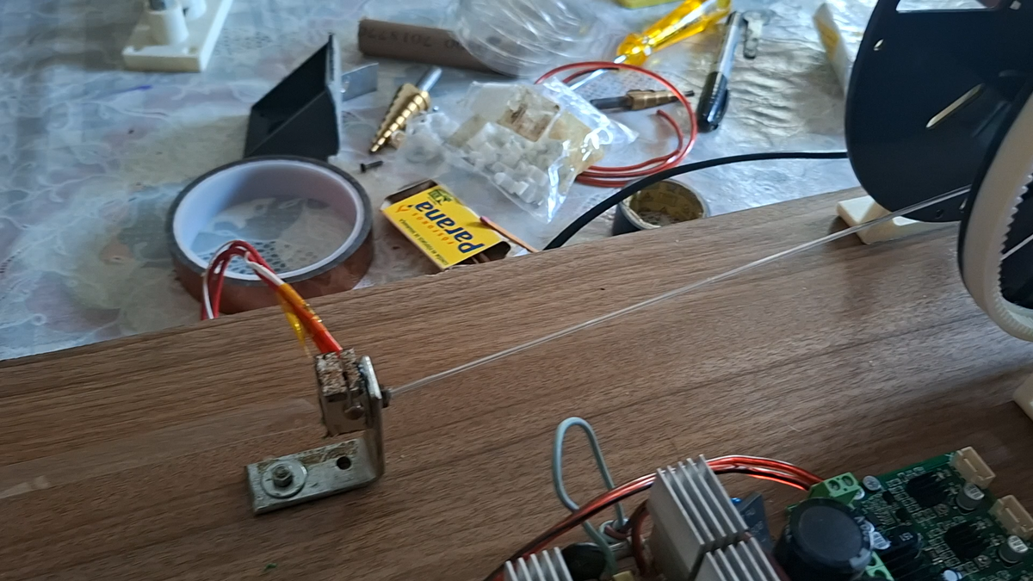
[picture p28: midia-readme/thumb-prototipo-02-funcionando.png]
Prototipo 02 funcionando corretamente


<a href="https://www.youtube.com/watch?v=FplmZ49YgME" target="_blank" rel="noopener noreferrer">Assistir no YouTube</a>

Este video registra o prototipo 02 ja funcionando corretamente, sem ajustes ou
detalhes pendentes para a operacao. Nesta fase, o equipamento conseguia executar
o processo de extrusao e bobinamento de forma estavel apos o inicio do G-code.

## Componentes visiveis

- Base de madeira maior para acomodar os subconjuntos.
- Suporte separado para o rolo/fita de PET na lateral esquerda.
- Conjunto de aquecimento/hotend posicionado antes do sistema de bobinamento.
- Fonte de alimentacao reaproveitada.
- Placa principal e eletronica reaproveitadas da Ender 3 Pro.
- Display LCD posicionado proximo ao carretel.
- Carretel adaptado com coroa dentada.
- Suporte impresso em 3D para sustentacao do carretel.

## Funcao desta versao

O objetivo do prototipo 02 e evoluir a organizacao fisica do equipamento,
separando melhor as etapas de alimentacao do material, aquecimento/extrusao,
controle eletronico e bobinamento.

Essa versao tambem ajuda a documentar a continuidade do desenvolvimento do
projeto, mostrando que a recicladora passou por iteracoes de montagem e ajuste
apos o primeiro prototipo.

## Subpastas

- `fotos/`: registros fotograficos do prototipo montado.
- `montagem/`: instrucoes e imagens das etapas de montagem dos subconjuntos.

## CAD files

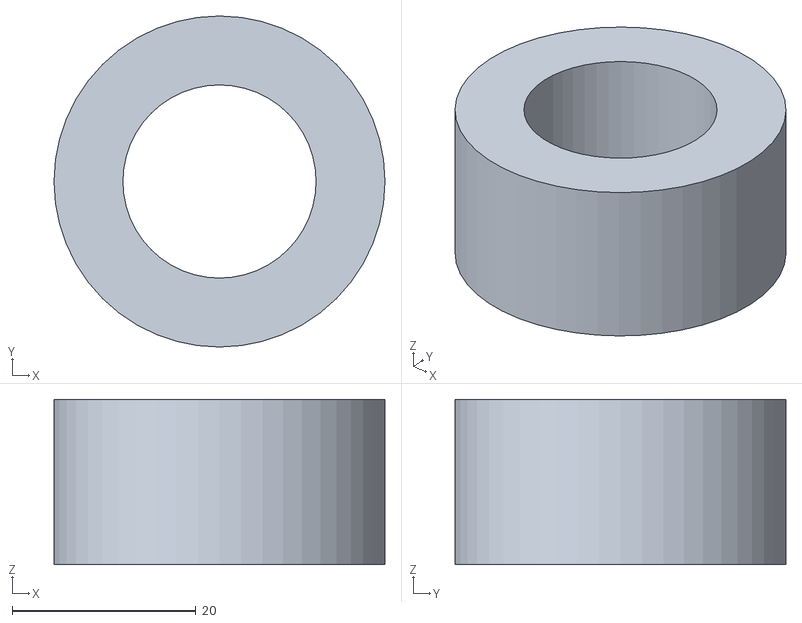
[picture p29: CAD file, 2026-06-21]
modelos-3d/stl/espacador-largo.stl
36.0 x 36.0 x 18.0

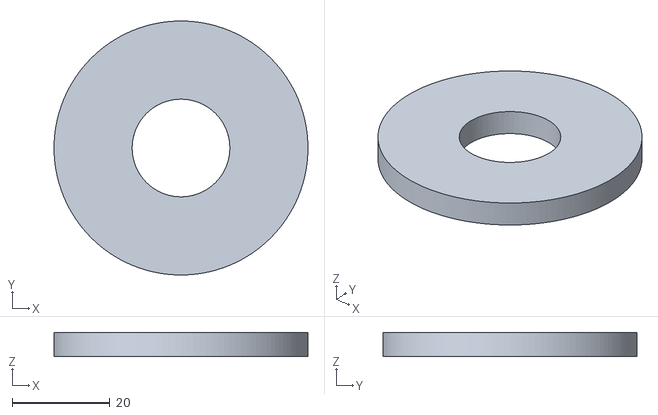
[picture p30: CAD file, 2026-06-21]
modelos-3d/stl/arruela-adaptadora.stl
52.0 x 52.0 x 5.00

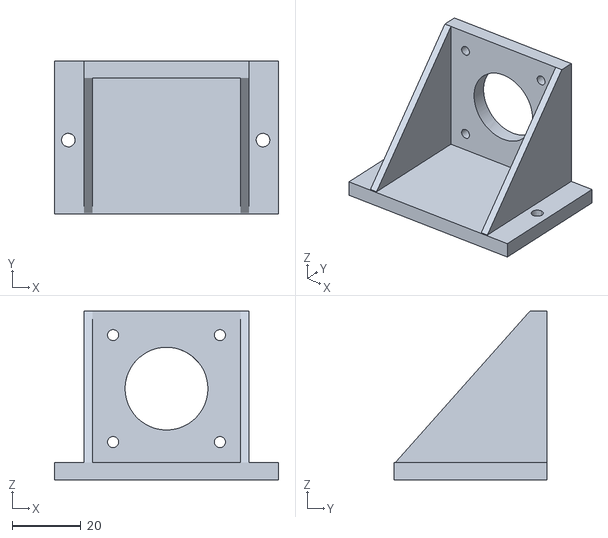
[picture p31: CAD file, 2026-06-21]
modelos-3d/stl/suporte-motor-nema17.stl
65.0 x 44.5 x 49.0

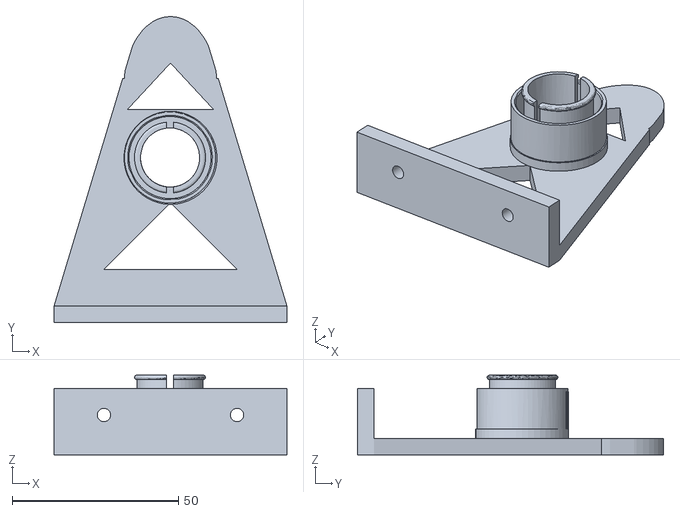
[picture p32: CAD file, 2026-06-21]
modelos-3d/stl/suporte-carretel-fita-pet.stl
70.0 x 92.0 x 24.0

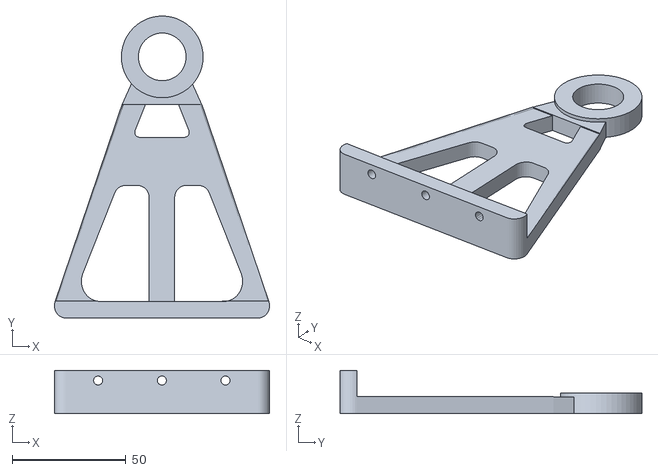
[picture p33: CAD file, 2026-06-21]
modelos-3d/stl/suporte-carretel-bobinador.stl
94.8 x 133.0 x 19.0

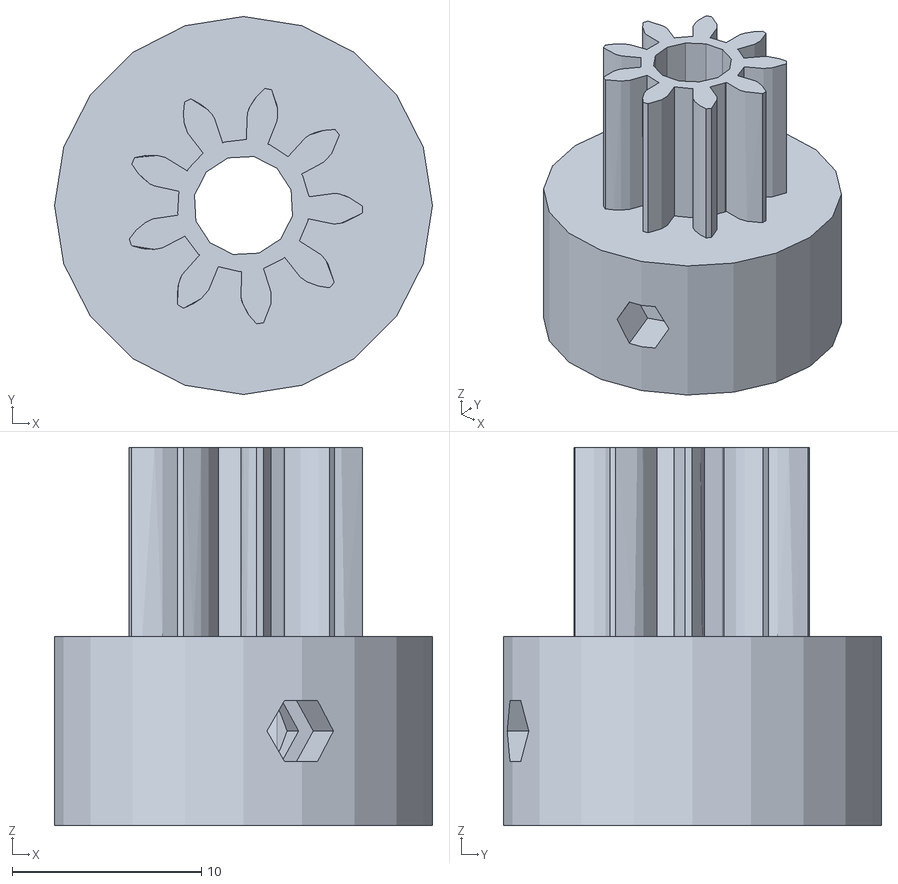
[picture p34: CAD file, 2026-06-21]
modelos-3d/stl/engrenagem-motor-nema17.stl
20.0 x 20.0 x 20.0

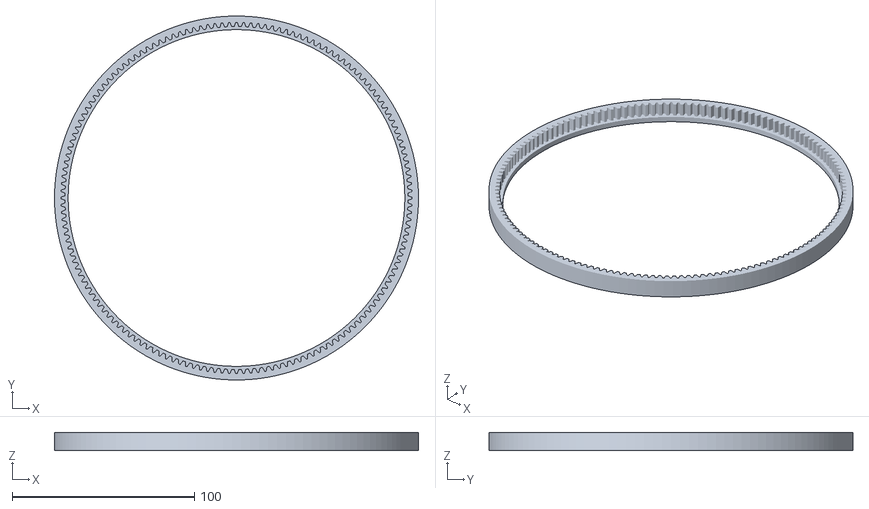
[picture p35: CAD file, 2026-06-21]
modelos-3d/stl/engrenagem-carretel.stl
200.0 x 199.9 x 10.0

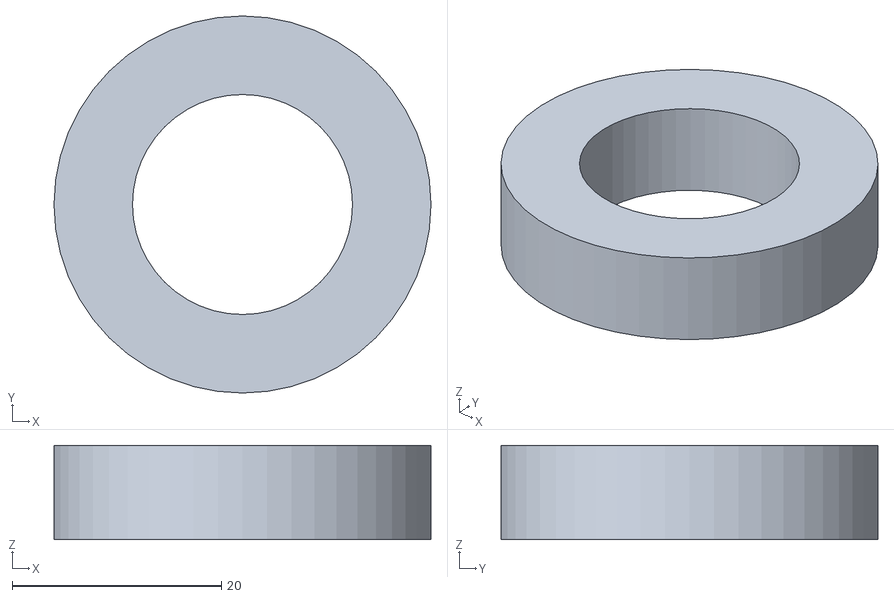
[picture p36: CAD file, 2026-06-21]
modelos-3d/stl/espacador-fino.stl
36.0 x 36.0 x 9.00

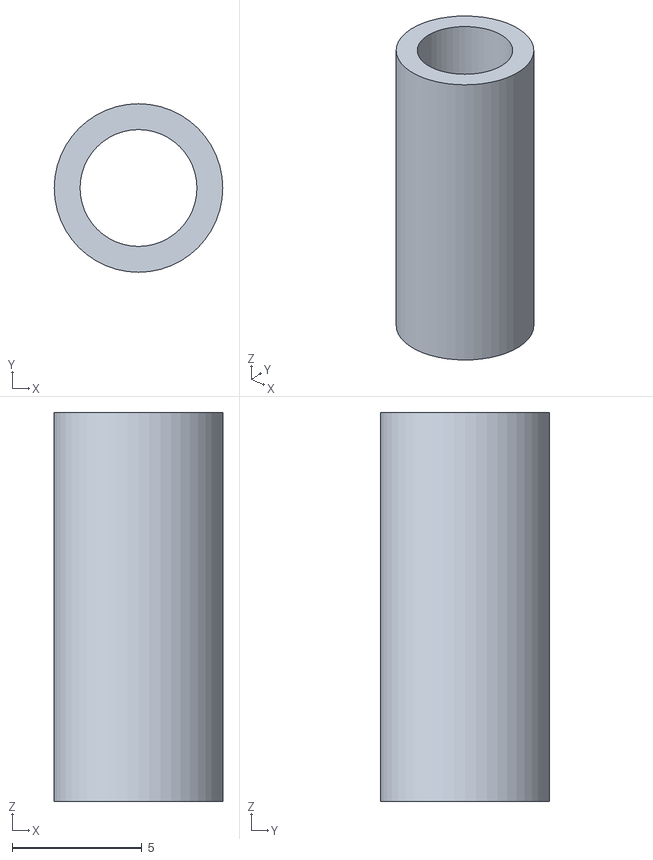
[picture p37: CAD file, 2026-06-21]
modelos-3d/stl/trava-filamento.stl
6.50 x 6.50 x 15.0

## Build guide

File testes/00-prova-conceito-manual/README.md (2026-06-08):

# Prova de conceito manual

Antes da construcao do equipamento, foi realizado um teste manual para verificar
se a ideia central do projeto era viavel: transformar uma fita de PET em
filamento usando aquecimento e tracao.

Neste teste inicial, foi utilizado o bloco gerador de calor do hotend E3D,
segurado com um alicate de pressao, e uma placa RAMPS para controlar o
aquecimento. A fita de PET era passada manualmente pelo bloco aquecido para
observar se o material amolecia, se fechava e se formava um filamento continuo.

Teste manual com bloco E3D e placa RAMPS

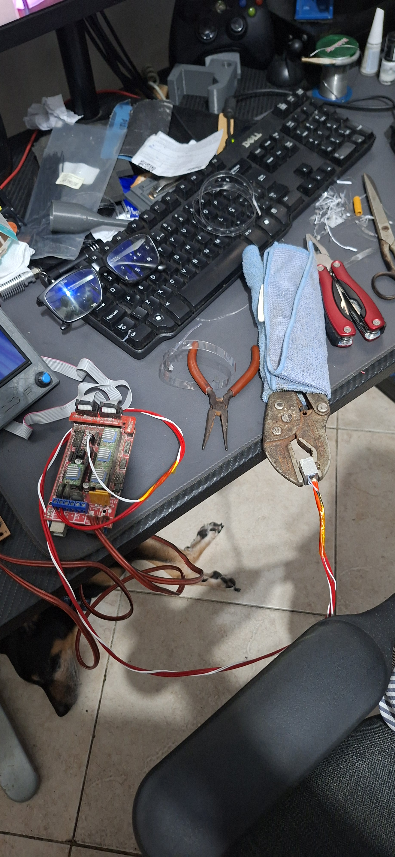
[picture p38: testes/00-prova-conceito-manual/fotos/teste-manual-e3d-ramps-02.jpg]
Segunda foto do teste manual com bloco E3D e placa RAMPS


Depois da formacao do primeiro trecho de filamento, o material foi levado ate a
impressora 3D para verificar se poderia ser aceito pelo sistema de alimentacao.
Esse teste avaliou dois pontos fundamentais: se o diametro estava proximo o
suficiente para passar pelo extrusor e se o material poderia trabalhar em uma
faixa de temperatura compativel com a impressora.

Primeiro filamento manual sendo testado na impressora

## Objetivo do teste

O objetivo era validar a possibilidade fisica do processo antes de investir tempo
na construcao da recicladora completa.

Se o PET conseguisse formar filamento manualmente a partir do bloco aquecido, o
projeto teria uma base tecnica para evoluir para uma versao mecanizada, com motor,
carretel, estrutura fixa e controle por G-code.

## Componentes usados

| Componente | Funcao no teste |
| --- | --- |
| Bloco aquecedor E3D | Aquecer e conformar a fita de PET. |
| Alicate de pressao | Segurar o bloco aquecido durante o teste manual. |
| Placa RAMPS | Controlar o aquecimento do conjunto. |
| Fonte de alimentacao | Alimentar a eletronica e o bloco aquecedor. |
| Fita de PET | Material testado para geracao de filamento. |

## Resultado esperado

O teste buscava confirmar que a fita de PET poderia:

- amolecer ao passar pelo bloco aquecido;
- dobrar e fechar sobre si mesma;
- sair em formato aproximado de filamento;
- manter continuidade suficiente para justificar a construcao da maquina.
- ser aceito pela impressora em relacao ao diametro e a temperatura de trabalho.

Essa etapa funcionou como ponto de partida experimental do projeto. A partir dela,
o desenvolvimento avancou para a criacao de uma estrutura propria de tracao,
bobinamento e controle.

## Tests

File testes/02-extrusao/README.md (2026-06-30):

# Extrusao e controle dimensional

Esta etapa documenta os testes de extrusao das fitas de PET preparadas a partir
de garrafas pos-consumo.

O objetivo foi avaliar se a fita de PET poderia ser aquecida, conformada e
bobinada em formato aproximado de filamento para impressao 3D, tendo como alvo o
diametro nominal de 1,75 mm.

## Procedimento geral

1. Preparar as garrafas PET, removendo rotulos, cola, sujeira e umidade.
2. Cortar as garrafas em fitas longitudinais.
3. Alimentar a fita no conjunto de aquecimento da recicladora.
4. Conduzir o material extrudado ate o carretel de armazenamento.
5. Deixar o filamento estabilizar por resfriamento em temperatura ambiente.
6. Medir o diametro em diferentes pontos usando paquimetro.

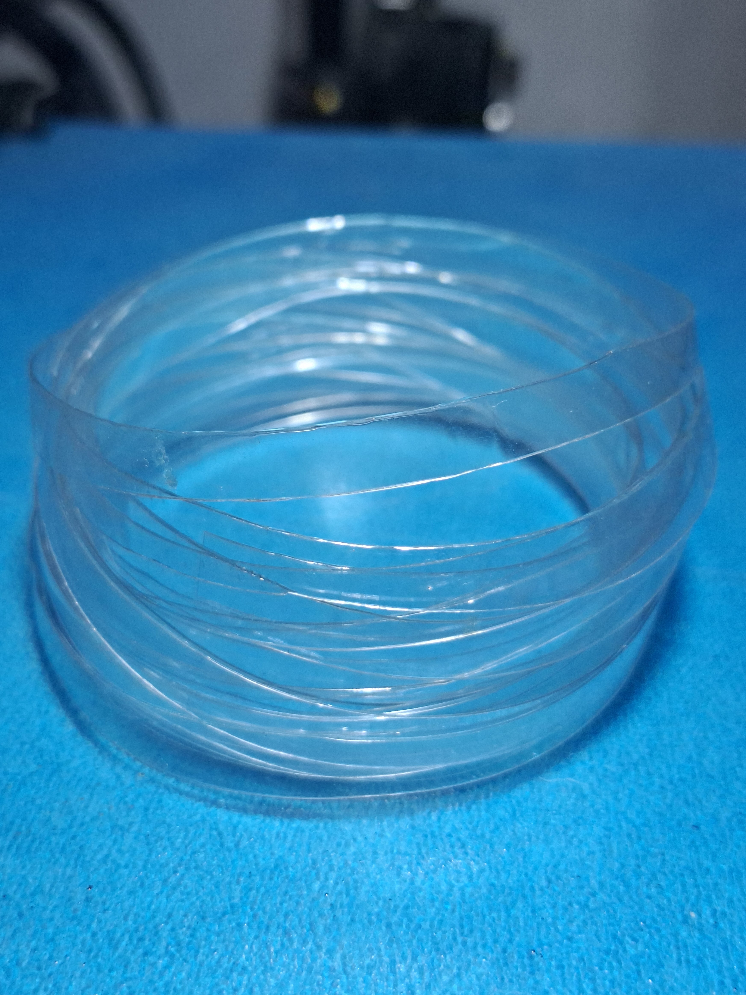
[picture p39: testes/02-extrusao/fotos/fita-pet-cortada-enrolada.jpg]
Fita PET cortada e enrolada


## Temperatura de extrusao

Durante os testes, a temperatura do bico variou entre 230 °C e 240 °C.

A temperatura de 230 °C foi registrada como a condicao mais estavel nos testes,
pois apresentou melhor acabamento superficial, aspecto visual mais cristalino e
formato dimensional mais uniforme.

## Controle dimensional

O filamento produzido foi medido com paquimetro apos o resfriamento. A avaliacao
considerou:

- proximidade com o alvo de 1,75 mm;
- variacao dimensional ao longo do filamento;
- ovalizacao;
- irregularidades superficiais;
- estabilidade visual do material produzido.

A tolerancia usada como referencia foi de aproximadamente ±0,07 mm em torno do
diametro nominal, seguindo a faixa usualmente adotada em filamentos comerciais e
em trabalhos correlatos sobre reciclagem de PET para impressao 3D.

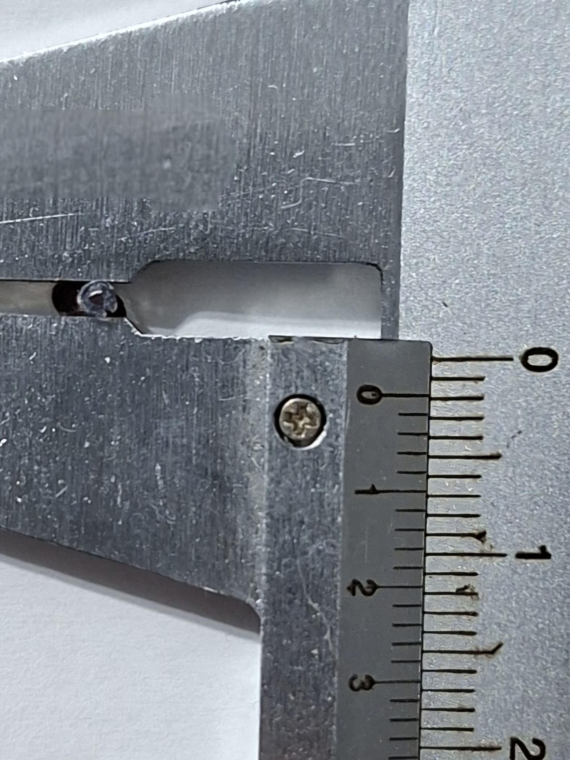
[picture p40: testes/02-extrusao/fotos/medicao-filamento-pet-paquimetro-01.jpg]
Medicao do filamento PET com paquimetro


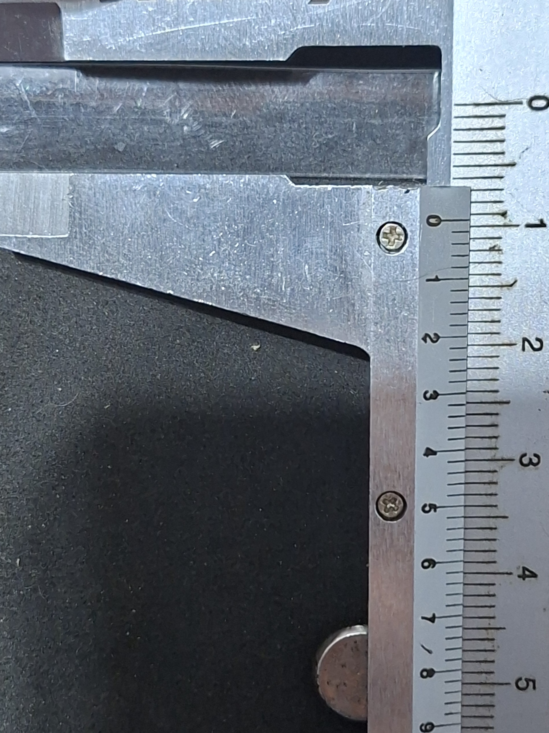
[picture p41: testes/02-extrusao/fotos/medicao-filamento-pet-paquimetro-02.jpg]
Segunda medicao do filamento PET com paquimetro


## Caracteristica do filamento produzido

O filamento gerado a partir da fita PET nao fica macico como um filamento
industrial. Durante a passagem pelo hotend, a fita amolece, dobra e fecha sobre
si mesma, formando uma estrutura semelhante a um tubo fino.

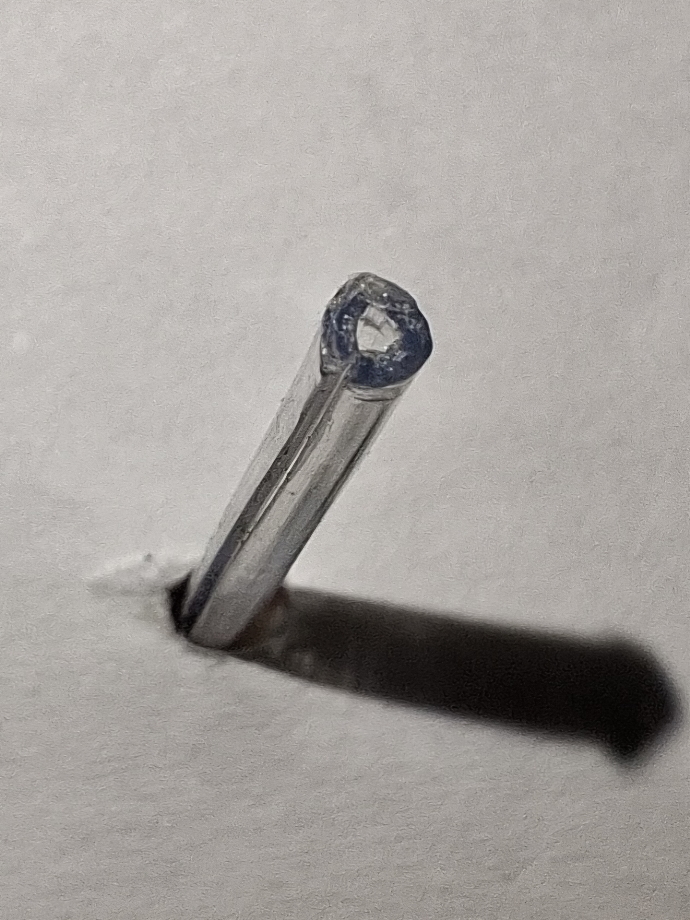
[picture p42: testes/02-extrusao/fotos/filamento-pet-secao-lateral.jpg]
Secao lateral do filamento PET produzido


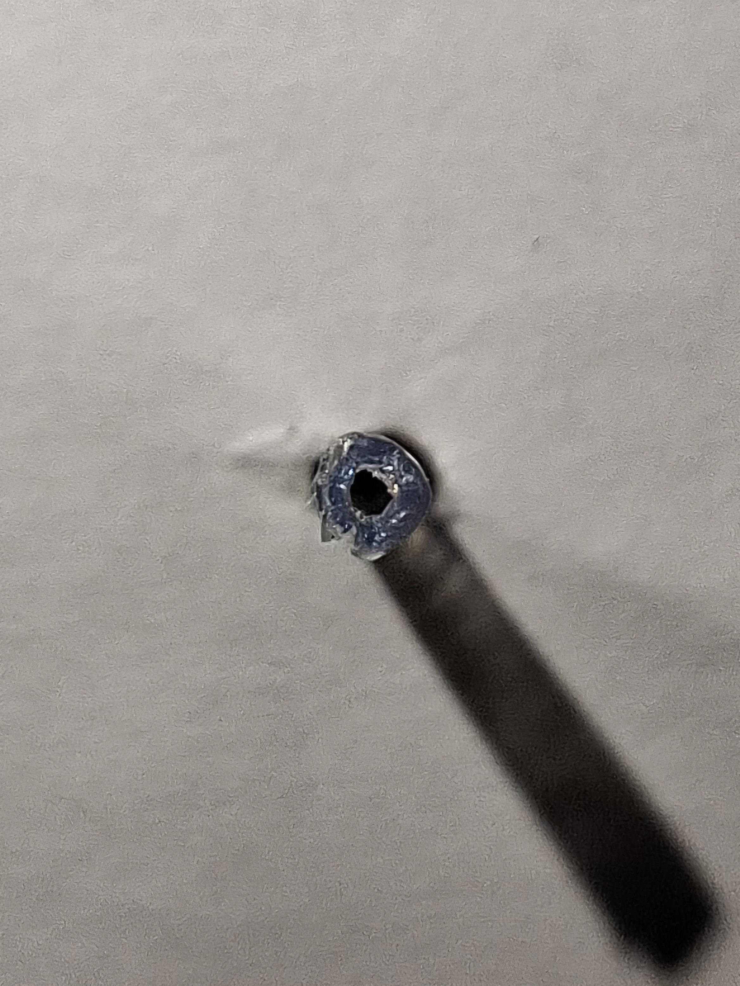
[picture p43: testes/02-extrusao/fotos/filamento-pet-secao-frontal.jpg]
Secao frontal do filamento PET produzido


Essa caracteristica explica parte dos ajustes necessarios na etapa de impressao,
principalmente o aumento de fluxo e a reducao da velocidade volumetrica maxima no
fatiador.

## Limitacoes dos dados

As medicoes desta etapa possuem carater experimental e estimativo. Os valores
podem variar conforme:

- marca, cor, espessura e composicao da garrafa;
- regularidade da fita cortada;
- umidade residual;
- estabilidade da temperatura;
- velocidade de tracao;
- alinhamento do conjunto de bobinamento;
- precisao dos instrumentos utilizados.

Os dados brutos desta etapa devem ser organizados em `dados/`.

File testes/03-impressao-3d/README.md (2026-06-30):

# Testes de impressão 3D com PET reciclado

Esta etapa documenta os testes realizados na impressora 3D usando o filamento de
PET produzido no projeto.

Depois da prova de conceito manual e da geração dos primeiros trechos de
filamento, o material foi testado na impressora para verificar se poderia ser
usado em uma impressão real. O objetivo inicial não era obter uma peça final
perfeita, mas entender o comportamento do material durante a alimentação,
extrusão e deposição.

## Primeiro teste de impressão

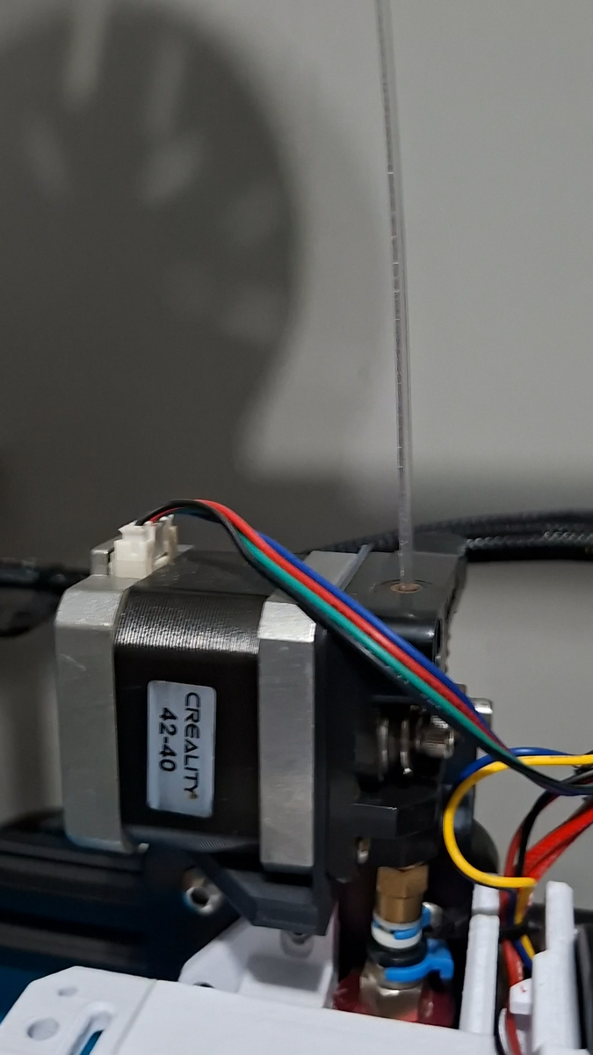
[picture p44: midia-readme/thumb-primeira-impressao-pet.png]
Vídeo da primeira impressão com filamento PET


<a href="https://www.youtube.com/shorts/xxXg9N6lQYA" target="_blank" rel="noopener noreferrer">Assistir no YouTube</a>

Este vídeo registra a primeira vez em que o filamento PET foi usado em uma
impressão 3D. O teste serviu para observar:

- se a impressora conseguiria puxar o filamento;
- se o diâmetro produzido era compatível com o caminho do extrusor;
- se a temperatura de trabalho era suficiente para fundir o PET;
- se seria necessário ajustar fluxo, velocidade ou temperatura;
- quais problemas apareceriam durante a primeira tentativa de impressão.

Algumas peças foram impressas para observar o comportamento do material em
geometrias simples, curvas, engrenagens e peças funcionais.

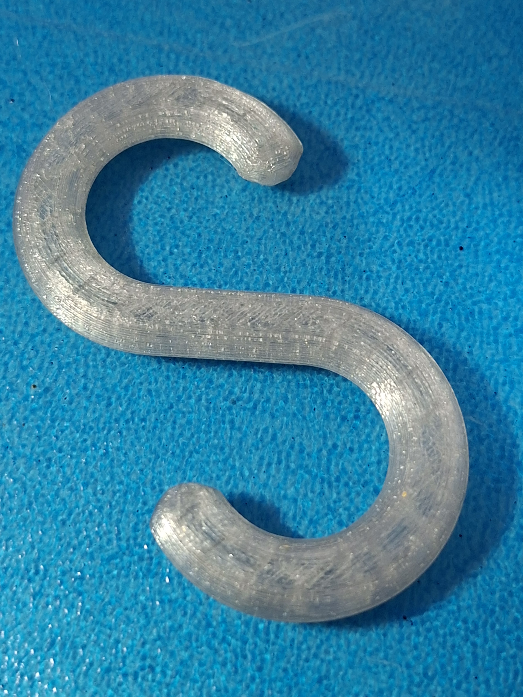
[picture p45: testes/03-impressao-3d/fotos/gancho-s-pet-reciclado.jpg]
Gancho em formato de S impresso com PET reciclado


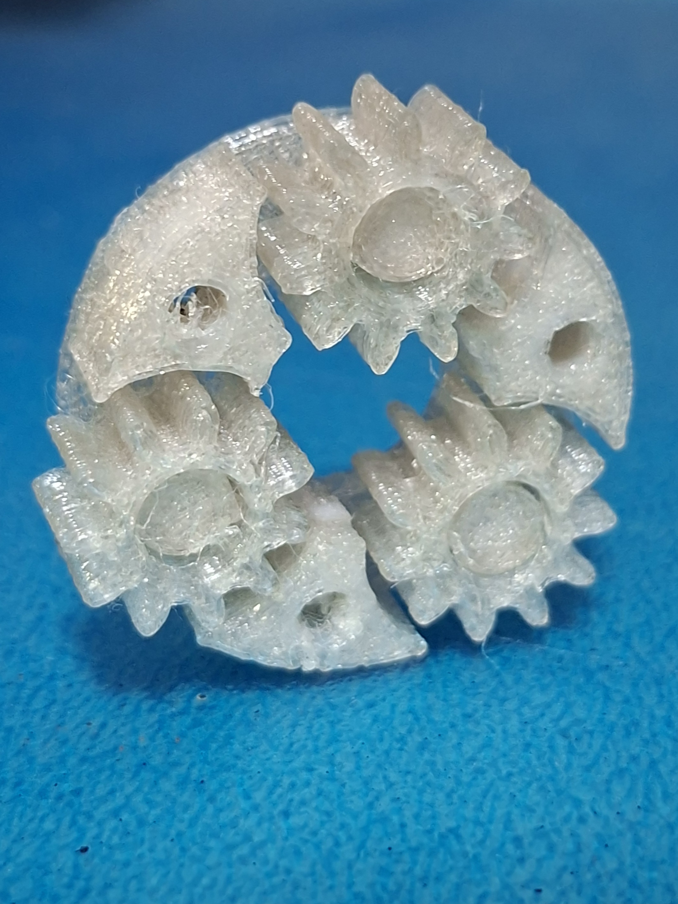
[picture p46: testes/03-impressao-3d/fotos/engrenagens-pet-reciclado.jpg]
Engrenagens impressas com PET reciclado


## Pontos avaliados

Durante os testes de impressão, os principais pontos de atenção foram:

- aderência inicial do material;
- continuidade da extrusão;
- fusão entre camadas;
- estabilidade do filamento no bico;
- necessidade de aumento do `Flow Ratio`;
- redução do `Max Volumetric Speed`;
- temperatura do hotend;
- temperatura da mesa.

## Teste com PET colorido

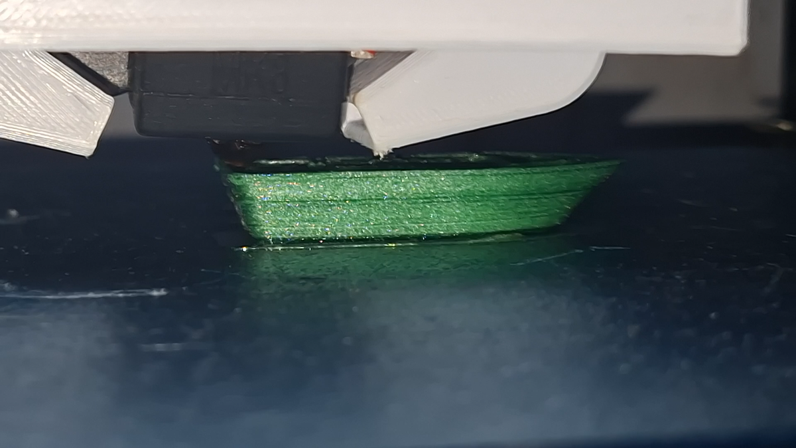
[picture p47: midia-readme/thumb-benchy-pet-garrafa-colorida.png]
Teste de impressão de Benchy com PET de garrafa colorida


<a href="https://www.youtube.com/watch?v=Nncd09i17XM" target="_blank" rel="noopener noreferrer">Assistir no YouTube</a>

Este teste utilizou a impressão de um barquinho Benchy para avaliar o
comportamento de garrafas PET coloridas. O objetivo era observar se o material
manteria translucidez após a extrusão e impressão, além de verificar se a cor da
garrafa causaria alguma diferença perceptível no comportamento do filamento.

Durante esse tipo de teste, os pontos de comparação incluem acabamento visual,
transparência/translucidez, aderência entre camadas, estabilidade da extrusão e
regularidade do material depositado.

Benchy impresso com PET de garrafa colorida

Cubo XYZ impresso com PET de garrafa colorida

## Peças funcionais

Além das peças de teste, o filamento reciclado foi usado em peças funcionais do
proprio projeto, como suportes e componentes auxiliares da recicladora.

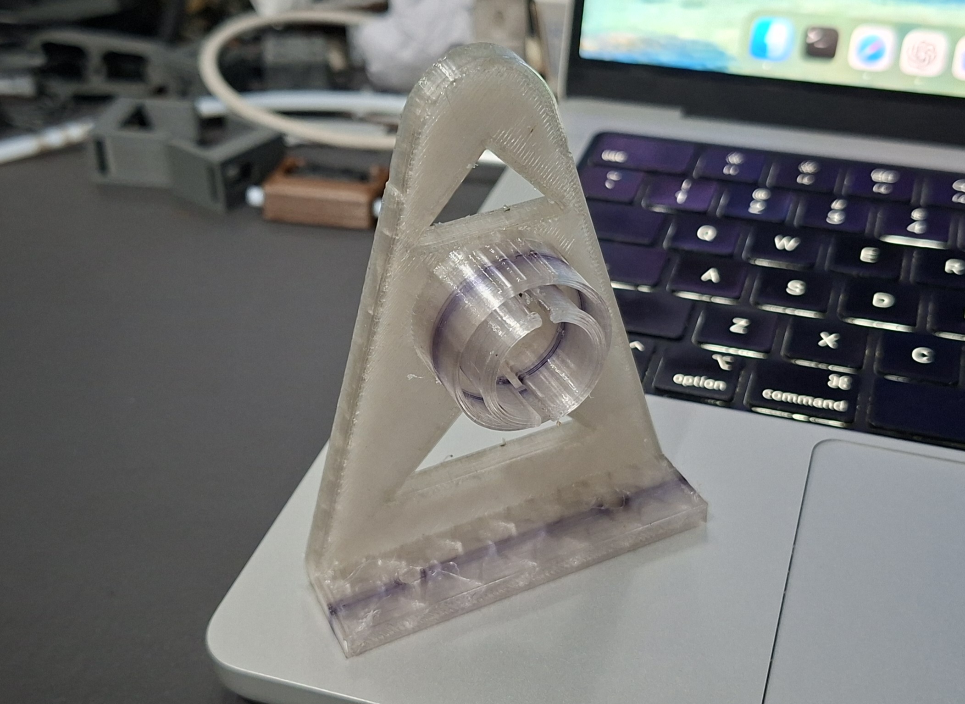
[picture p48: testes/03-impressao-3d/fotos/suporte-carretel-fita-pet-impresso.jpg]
Suporte do carretel da fita PET impresso com PET reciclado


Suporte do switch da fita PET montado

## Relação com os parâmetros de impressão

Como o filamento produzido a partir de fita PET não é totalmente maciço, foi
necessário compensar a quantidade de material no fatiador. Nos testes do projeto,
isso levou ao aumento do fluxo e à redução da velocidade volumétrica máxima para
evitar falta ou excesso de material durante a impressão.

Os parâmetros detalhados estão registrados em:

[parametros](parametros/).

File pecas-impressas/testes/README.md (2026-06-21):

# Pecas de teste

Esta pasta documenta pecas impressas para avaliar o comportamento do filamento
PET reciclado durante a impressao 3D.

## Modelos usados

| Peca | Foto | Finalidade |
| --- | --- | --- |
| Cubo XYZ | [`fotos/cubo-xyz-pet-reciclado.jpg`](fotos/cubo-xyz-pet-reciclado.jpg) | Avaliar dimensao, estabilidade de deposicao e coerencia geometrica. |
| Benchy | [`fotos/benchy-pet-reciclado.jpg`](fotos/benchy-pet-reciclado.jpg) | Avaliar acabamento, temperatura, velocidade, fusao entre camadas e comportamento em geometrias variadas. |

Cubo XYZ impresso com PET reciclado

Benchy impresso com PET reciclado

## Criterios observados

- aderencia da primeira camada;
- estabilidade da extrusao;
- fusao entre camadas;
- acabamento visual;
- dimensoes finais;
- comportamento em curvas, pontes e detalhes pequenos;
- necessidade de ajustes de temperatura, fluxo e velocidade volumetrica.

Esses testes serviram para encontrar um conjunto minimo de parametros viaveis
para uso do filamento reciclado em impressora FDM.

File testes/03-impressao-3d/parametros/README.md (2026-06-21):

# Parametros de impressao com PET reciclado

Esta pasta documenta os principais ajustes usados no Orca Slicer para imprimir
com o filamento produzido a partir de garrafas PET.

O filamento reciclado nao se comporta exatamente como um filamento comercial
macico. Por ser formado a partir de uma fita PET dobrada e conformada pelo calor,
o material pode apresentar interior oco, ovalizacao e variacoes dimensionais.
Por isso, os parametros de impressao precisam compensar a diferenca de fluxo,
fusao e estabilidade do material.

## Ajustes principais

| Parametro | Valor/ajuste usado | Motivo |
| --- | --- | --- |
| Temperatura do hotend | Pelo menos 280 °C | Melhorar a fusao entre camadas do PET reciclado. |
| Temperatura da mesa | 70 °C a 80 °C | Melhorar a aderencia inicial, variando conforme o tamanho da peca. |
| Flow Ratio | Aumento aproximado de 25% a 35% | Compensar o interior oco e a menor quantidade efetiva de material depositado. |
| Max Volumetric Speed | Reducao para cerca de 1/3 do valor original | Evitar que a demanda de material exceda a capacidade real de fusao e deposicao. |

## Pontos avaliados nos testes

- aderencia inicial na mesa;
- continuidade da extrusao;
- fusao entre camadas;
- estabilidade do filamento no bico;
- acabamento visual;
- coerencia dimensional das pecas;
- comportamento em modelos de teste como Cubo XYZ e Benchy.

## Observacao

Os valores acima foram obtidos de forma experimental e devem ser tratados como
ponto de partida. Novos lotes de filamento podem exigir ajustes adicionais,
principalmente por diferencas entre garrafas, largura da fita, umidade residual e
regularidade dimensional do filamento produzido.

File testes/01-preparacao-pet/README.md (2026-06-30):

# Preparacao das garrafas PET

Esta etapa documenta o preparo das garrafas PET pos-consumo antes do corte em
tiras. A preparacao correta reduz contaminacoes, melhora a regularidade do corte
e evita que sujeira, cola ou umidade prejudiquem a extrusao do material.

## Video do processo

O video mostra a preparacao da garrafa PET, o corte inicial, o fatiamento em
tiras e o enrolamento da fita no carretel para uso posterior na recicladora.

<a href="https://www.youtube.com/shorts/VywLTE21x4Y" target="_blank" rel="noopener noreferrer">Assistir ao video no YouTube</a>

## Limpeza e remocao do rotulo

Limpeza e remocao do rotulo da garrafa PET

Antes de remover o fundo da garrafa, o recipiente deve ser limpo e seco. A garrafa
e lavada por dentro e por fora com agua e detergente neutro para remover residuos
organicos, poeira e sujeira superficial.

Em seguida, devem ser retirados todos os rotulos, adesivos e aneis plasticos que
nao fazem parte do corpo principal da garrafa. A remocao do rotulo e importante
porque restos de papel, plastico adesivo e cola podem contaminar a fita de PET,
aderir a ferramenta de corte ou chegar ao hotend durante a extrusao.

Caso a garrafa ainda apresente cola do rotulo, a area deve ser limpa novamente
ate que a superficie fique lisa. No projeto, tambem foi usado oleo de linhaca
para ajudar na remocao de residuos de cola antes da lavagem final.

Depois da retirada do rotulo e da limpeza, a garrafa deve ser enxaguada e seca.
A secagem pode ser feita em local arejado ou com pano seco, evitando que umidade
residual acompanhe o material ate a etapa de extrusao.

## Remocao do fundo da garrafa

Remocao do fundo da garrafa PET

Com a garrafa limpa, sem rotulo e seca, o fundo e removido para permitir o encaixe
correto na ferramenta de corte das tiras de PET.

No projeto, o fatiamento da garrafa em tiras foi feito com o
[Simple PET Bottle Cutter](https://makerworld.com/pt/models/98441-simple-pet-bottle-cutter#profileId-111492),
disponivel no MakerWorld.

### Procedimento

1. Posicionar a tesoura na base da garrafa.
2. Cortar cuidadosamente o fundo da garrafa.
3. Conferir se a abertura ficou livre para o uso na ferramenta de corte.
4. Secar novamente a parte interna, se necessario.

## Resultado esperado

Ao final desta etapa, a garrafa deve estar:

- limpa por dentro e por fora;
- sem rotulo, adesivos, tampa e aneis plasticos;
- sem residuos aparentes de cola;
- seca;
- com o fundo removido;
- pronta para ser processada na ferramenta que gera as fitas de PET.

Esses cuidados aumentam a chance de obter fitas mais limpas e regulares, o que
facilita a passagem pelo hotend e melhora a estabilidade do filamento produzido.

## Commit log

2026-06-08 Base do projeto
    [pecas-impressas-3d.csv]
2026-06-20 fix: alteracao de referencia de videos
2026-06-21 fix: alteracao de dados e estrutura do projeto
2026-06-21 Add printable STL files
    [arruela-adaptadora.stl, engrenagem-carretel.stl, engrenagem-motor-nema17.stl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]
2026-06-21 Remove duplicated printed parts CSV
    [pecas-impressas-3d.csv]
2026-06-21 Move assembly docs to prototype 02
2026-06-21 Add PET print test photos
2026-06-21 Add prototype replacement gear photo
2026-06-21 Add functional PET printed parts photos
2026-06-21 Add PET switch support photos and video link
2026-06-28 Adiciona demonstracao de funcionamento
2026-06-30 style: acertos de dados e fotos novas
